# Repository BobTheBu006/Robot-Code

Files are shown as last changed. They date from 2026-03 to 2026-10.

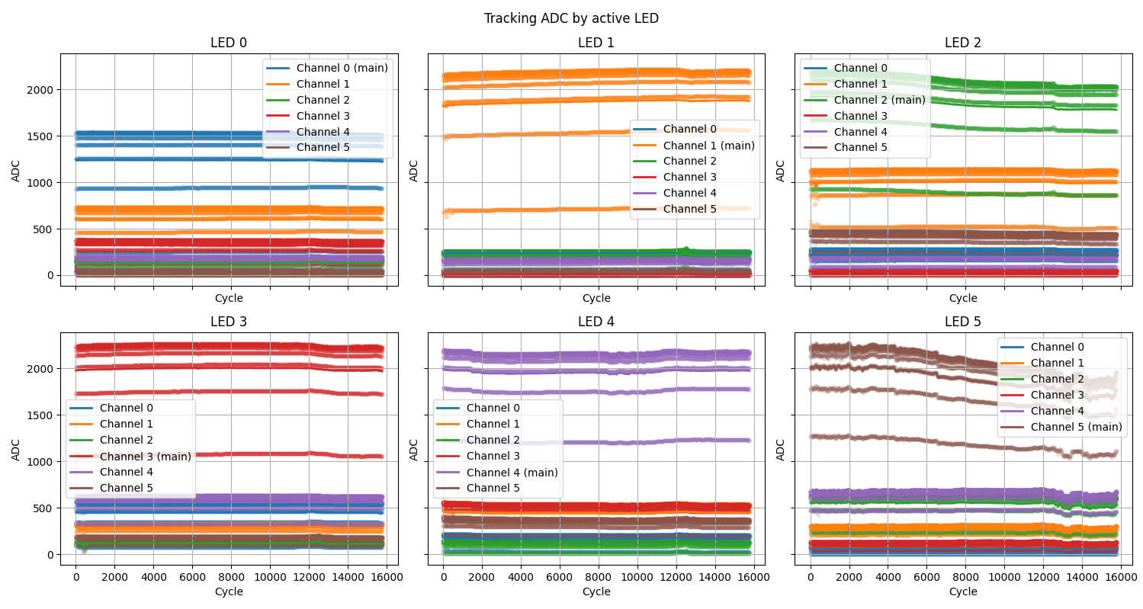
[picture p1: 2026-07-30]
OD tests/Figure_2.png

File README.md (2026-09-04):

# Modular Robot Control Platform

This repository is the working prototype for a modular, open-source lab robot platform aimed at underfunded research labs, universities, and small teams that need repairable automation built from cheap, available parts.

The long-term target is an extensible alternative to closed lab automation systems. The Raspberry Pi coordinates the robot, the browser UI edits workflows and hardware maps, and ESP32 controllers run the low-level motor, actuator, and sensor code.

## Thesis

The complete MSc thesis describing the robot's motivation, mechanical and electronic design, software architecture, commissioning, and experimental evaluation is available here:

- [Download the MSc thesis (PDF)](docs/thesis/MSc_Thesis.pdf)

## Start Here

For future AI coding agents and maintainers:

- Read `docs/ARCHITECTURE_CONTRACTS.md` before changing schemas, workflow behavior, firmware generation, or module boundaries.
- Read `docs/BACKWARDS_COMPATIBILITY.md` before changing saved workflows, hardware maps, manifests, or firmware protocols.

## Current Capabilities

- FastAPI backend with health, robot state, camera, hardware map, function discovery, ESP32 builder, and workflow storage routes.
- Vite + React + TypeScript frontend.
- React Flow workflow editor with built-in flow controls, advanced function blocks, and compound function blocks.
- Hardware Map editor for Raspberry Pi, ESP32 controllers, motors, servos, sensors, and grouped hardware assemblies.
- Function manifests can declare hardware dependencies so the Hardware Map and workflow blocks can reference the same logical devices.
- Workflow runs flash the ESP32 boards used by the workflow before execution.

## Repository Structure

```text
.
|-- backend/
|-- docs/
|-- firmware/
|-- frontend/
|-- functions/
|-- hardware/
|-- hardware-map.json
`-- workflows/
```

## Quick Start

Prerequisites:

- Python 3.11+ for the backend
- Node.js 20+ with `npm` for the frontend
- Arduino CLI for ESP32 build/flash flows

### Start Everything

Clone the repository and enter its directory:

```text
git clone https://github.com/BobTheBu006/Robot-Code.git
cd Robot-Code
```

On Windows 11:

```powershell
start-all.bat
```

On Raspberry Pi OS / Linux:

```bash
./start-all.sh
```

Frontend UI:

```text
http://127.0.0.1:5173
```

Backend API:

```text
http://127.0.0.1:8000
```

### Start Backend Only

```powershell
start-backend.bat
```

### Start Frontend Only

```powershell
start-frontend.bat
```

## Development Model

The intended architecture is modular:

- Hardware Map is the source of truth for physical USB ports, controllers, devices, pins, and hardware groups.
- Function manifests declare the devices they require.
- Basic workflow blocks are generated from hardware devices.
- Advanced functions can use controller firmware and backend handlers, but they must still declare hardware dependencies.
- Compound functions can be built from connected workflow blocks and should become exportable/shareable modules later.
- Firmware flashed to each controller should eventually be generated from the Hardware Map plus every workflow block that needs that controller.

Do not add one-off pin lists or hidden hardware assumptions inside functions. If a function uses a motor, servo, sensor, camera, API service, or future device, declare it through the module/function contract so the UI, backend, firmware, and tests can reason about it.

## License

This repository is licensed under Apache License 2.0 unless a file or module says otherwise. See `LICENSE` and `docs/LICENSE_POLICY.md`.

Future hardware/CAD/electronics packages should carry an explicit open hardware license, with `CERN-OHL-S-2.0` as the preferred default when the goal is to keep hardware improvements open.

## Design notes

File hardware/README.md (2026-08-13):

# Hardware

This directory contains the mechanical, electrical, and manufacturing files for
the modular laboratory robot.

## Structure

- `mechanical/`: original CAD, neutral STEP exports, and print-ready STL files.
- `electronics/`: schematics, PCB design files, and wiring documentation.
- `bom/`: bills of materials and sourcing information.
- `third-party/`: attribution and licence records for externally sourced models.

Each mechanical assembly uses the same export structure:

```text
assembly-name/
|-- source/  # Editable native CAD, such as F3D or F3Z
|-- step/    # Neutral CAD exchange files
`-- stl/     # Current print-ready parts
```

Use descriptive lowercase filenames with hyphens. Git records normal design
history, so avoid names such as `final-final` unless two revisions must remain
available at the same time.

Original hardware files should use the hardware licence declared by the
repository. Do not add third-party models until their source, author, licence,
and modification status have been recorded in `third-party/README.md`.

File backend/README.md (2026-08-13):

# Backend

FastAPI backend for the local robot-control app.

Read `../docs/ARCHITECTURE_CONTRACTS.md` and `../docs/BACKWARDS_COMPATIBILITY.md` before changing function discovery, hardware map sync, workflow execution, firmware flashing behavior, or persistent data contracts.

## Run locally

On Raspberry Pi OS / Linux:

```bash
cd "/home/robot/robot control/Robot-Code"
./start-backend.sh
```

On Windows 11:

```powershell
cd "C:\BOB\masters\Thesis\Robot Code"
start-backend.bat
```

Or run it directly:

Raspberry Pi OS / Linux:

```bash
cd "/home/robot/robot control/Robot-Code/backend"
python3 -m venv .venv
./.venv/bin/python -m pip install -r requirements.txt
./.venv/bin/python -m uvicorn app.main:app --reload
```

Windows 11:

```powershell
cd "C:\BOB\masters\Thesis\Robot Code\backend"
.\.venv\Scripts\python.exe -m pip install -r requirements.txt
.\.venv\Scripts\python.exe -m uvicorn app.main:app --reload
```

The API will be available at `http://127.0.0.1:8000`.

## Run the tests

Install the development requirements, then run the standard-library test suite:

Raspberry Pi OS / Linux:

```bash
./.venv/bin/python -m pip install -r requirements-dev.txt
./.venv/bin/python -m unittest discover -s tests -t .
```

Windows 11:

```powershell
.\.venv\Scripts\python.exe -m pip install -r requirements-dev.txt
.\.venv\Scripts\python.exe -m unittest discover -s tests -t .
```

## Endpoints

- `GET /health`
- `GET /api/robot/state`
- `POST /api/robot/state/mock-update`
- `GET /api/camera/status`
- `GET /api/camera/frame`
- `GET /api/camera/stream`
- `GET /api/functions`
- `POST /api/functions/{function_id}/test`
- `POST /api/esp32-builder/workflow-firmware/plan`
- `GET /api/tools/syringe/status`
- `POST /api/tools/syringe/dispense`

## Camera feed

The backend can expose a USB camera to the frontend as an MJPEG stream.

Camera environment variables:

- `CAMERA_DEVICE=0`
- `CAMERA_FRAME_WIDTH=1280`
- `CAMERA_FRAME_HEIGHT=720`
- `CAMERA_FPS=15`

If the camera feed reports that OpenCV is unavailable, reinstall backend dependencies:

```bash
cd "/home/robot/robot control/Robot-Code/backend"
./.venv/bin/python -m pip install -r requirements.txt
```

## Syringe ESP32 control

The backend can send a 7-head syringe dispense command to an ESP32 over serial.

Defaults:

- calibration file: `/home/robot/robot control/syringe control code/calibration.json`
- serial port: first match from `/dev/ttyUSB*` or `/dev/ttyACM*`
- baud rate: `115200`
- command format: `json`

Optional environment variables:

- `SYRINGE_CALIBRATION_FILE`
- `SYRINGE_SERIAL_PORT`
- `SYRINGE_BAUD_RATE`
- `SYRINGE_SERIAL_TIMEOUT_SECONDS`
- `SYRINGE_COMMAND_FORMAT`

Example request:

```bash
curl -X POST http://127.0.0.1:8000/api/tools/syringe/dispense \
  -H "Content-Type: application/json" \
  -d '{"A":150,"B":25,"C":0,"D":100,"E":0,"F":10,"G":75}'
```

## Function discovery

Robot execution blocks are discovered from subfolders in `backend/app/functions/`.

Each function folder must contain:

- `manifest.json`
- `handler.py`
- `requirements.txt`

Example structure:

```text
app/functions/
  dispense/
    manifest.json
    handler.py
    requirements.txt
```

The `GET /api/functions` endpoint scans those folders, validates their manifests, and returns the block metadata the workflow editor uses to build robot-action nodes.

`POST /api/functions/{function_id}/test` loads the function folder's `handler.py` and calls `execute(context, inputs)` in test mode so the workflow editor can preview block behavior without introducing a full execution engine yet.

Function manifest outputs are workflow control-flow paths, not data fields. Normal robot actions should expose a single `next` output with `"type": "flow"`; the Workflow Editor can add a separate `error` output from block settings. Branching blocks such as if/else or loops may expose multiple flow outputs. Handler return values such as status strings, measurements, or raw controller replies should remain in the result payload and should not be listed as graph outputs.

The Workflow Editor separates blocks into three groups:

- Basic blocks: triggers, logic blocks, and hardware-map generated servo/stepper/sensor actions.
- Advanced functions: backend-discovered robot functions such as gantry calibration and syringe dispensing.
- Compound functions: directly connected canvas blocks collapsed through the canvas context menu. Compound functions preserve their external flow outputs and can be expanded back into editable blocks.

Advanced function manifests may declare `hardware_devices`. Each declared motor, servo, or sensor is synchronized into the Hardware Map using stable device IDs and `function_input_key` pin links. The Workflow Editor then generates the matching basic hardware block from the Hardware Map, so a custom function and its basic move/read block point at the same physical USB controller and GPIO pins.

Advanced function manifests may also declare `firmware_requirements`. These identify the ESP32 routines, source files, protocols, and required logical devices that workflow-aware firmware planning collects per controller before flashing. The planner endpoint validates that referenced firmware sources stay inside the selected board workspace and exist before the workflow runner starts flashing boards.

## Mock update example

```powershell
Invoke-RestMethod -Method Post `
  -Uri http://127.0.0.1:8000/api/robot/state/mock-update `
  -ContentType "application/json" `
  -Body '{
    "machine_state": "running",
    "current_workflow": "tray_loading",
    "current_step": 4,
    "gantry": { "x": 210, "y": 85, "z": 32 },
    "sensor_values": [],
    "alarms": [
      {
        "code": "low_air",
        "message": "Compressed air pressure below threshold.",
        "severity": "warning",
        "active": true
      }
    ]
  }'
```

## Current design

- `app/api/routes/` contains route definitions
- `app/models/` contains Pydantic models for robot state and updates
- `app/services/` contains robot state, hardware map, function discovery, workflow storage, and ESP32 builder logic

This keeps routing, data contracts, and application logic separate from the start.

For future changes, keep persistent schema updates versioned and covered by migration tests. See `../docs/BACKWARDS_COMPATIBILITY.md`.

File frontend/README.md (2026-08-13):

# Frontend

Vite + React + TypeScript dashboard for the local robot-control app.

Requires Node.js 20+ with `npm` available on your `PATH`.

Read `../docs/ARCHITECTURE_CONTRACTS.md` and `../docs/BACKWARDS_COMPATIBILITY.md` before changing workflow, hardware map, block behavior, or persistent data contracts.

## Run locally

On Raspberry Pi OS / Linux:

```bash
cd "/home/robot/robot control/Robot-Code"
./start-frontend.sh
```

On Windows 11:

```powershell
cd "C:\BOB\masters\Thesis\Robot Code"
start-frontend.bat
```

Or run it directly:

Raspberry Pi OS / Linux:

```bash
cd "/home/robot/robot control/Robot-Code/frontend"
cp .env.example .env
npm install
npm run dev
```

Windows 11:

```powershell
cd "C:\BOB\masters\Thesis\Robot Code\frontend"
copy .env.example .env
npm.cmd install
npm.cmd run dev
```

## Environment

```env
VITE_API_BASE_URL=
```

Leave `VITE_API_BASE_URL` blank for normal development. The frontend will call `/api/...` on the same origin, and Vite proxies those requests to the FastAPI backend at `http://127.0.0.1:8000`. This is the correct setup when opening the UI from another computer on the Raspberry Pi network, because browser-side `127.0.0.1` would otherwise point at the other computer.

Once the backend camera route is enabled, the dashboard camera panel will pull its live stream from `/api/camera/stream`.

## Available scripts

- `npm run dev`
- `npm run build`
- `npm run preview`

## Current features

- backend connection status
- robot state polling every second
- robot state card with loading, success, and error feedback
- camera status and feed placeholder/live stream support
- Hardware Map editor for Raspberry Pi, ESP32 controllers, devices, pins, and hardware groups
- Workflow Editor with basic, advanced, and compound function blocks
- hardware-map generated basic blocks for steppers, servos, and sensors
- per-block inspector editing and function test actions
- palette block hide/unhide behavior
- pre-run ESP32 flashing for boards used by the workflow

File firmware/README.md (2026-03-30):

# Firmware Placeholder

This folder is reserved for future ESP32 firmware projects.

Likely future contents:

- one folder per ESP32 board
- shared protocol definitions
- hardware pinout notes
- board responsibilities

Nothing is implemented here yet on purpose.

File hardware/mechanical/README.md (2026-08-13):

# Mechanical Design

Mechanical files are grouped by robot assembly. Keep editable CAD in `source/`,
neutral exports in `step/`, and only current print-ready meshes in `stl/`.
The `whole-robot/` directory contains the maintained partial assembly that brings
the major subsystems together.

When adding a part, record its quantity, material, print orientation, support
requirements, and assembly notes in the relevant assembly directory.

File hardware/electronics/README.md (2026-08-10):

# Electronics

- `schematics/`: circuit and connection diagrams.
- `pcb/`: editable PCB projects and fabrication outputs.
- `wiring/`: cable, connector, pinout, and harness documentation.

Machine-specific secrets and local runtime configuration must not be stored
here.

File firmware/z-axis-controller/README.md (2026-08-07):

# Dual Z-Axis Controller Firmware

> **The canonical source now lives in the builder workspace:**
> `functions/esp 32 code/esp32 controller-ykkl80/firmware/main.ino`
>
> That is the copy the app compiles and flashes. Edit it there, not here.
> This directory is kept only as the recovery archive of where the firmware
> came from; the copy in it may lag behind.

Firmware for the "Double Z axis and pumps" ESP32 (hardware map board
`controller-ykkl80`). Drives two Z motors; the four limit switches are NOT
wired to this board - they go straight to Raspberry Pi GPIO, and the Pi
decides when to stop (see `backend/app/services/hybrid_z_axis.py`).

Originally recovered from `functions/esp 32 code/esp32 ttyUSB1/firmware/main.ino`,
the combined CoreXY+Z controller firmware from before the XY gantry moved to
Raspberry Pi GPIO. It still contains the XY/CoreXY command handlers; they are
harmless to leave in (never invoked) since this board only has Z motors wired.

Serial protocol (115200 baud):
- `SET Z PINS <leftStep> <leftDir> <rightStep> <rightDir>`
- `STEP Z <leftSteps> <rightSteps> <rpm> <trapezoidFlag> <accelRpmPerSec>`
  - Open-loop move; this board reads no limit switches for it. Replies
    `OK STEP Z <leftDone> <rightDone>` with the steps actually travelled, or
    `OK STOP STEP Z <leftDone> <rightDone>` if the host sent `STOP` mid-move.
  - The host seeks a switch by commanding the whole travel and sending `STOP`
    the instant its own GPIO sees the switch trip. `runDualAxisMove` checks for
    `STOP` between every step, so overtravel is one step period, and the axis
    moves smoothly instead of hopping between short bursts.
- `STOP` - abort the move in progress.
- `PING` -> `PONG`

**Do not send this board the limit-switch pin numbers from the Hardware Map.**
Those are Raspberry Pi GPIO numbers. `SET Z LIMITS` with them configures ESP32
GPIO 6, which is wired to this chip's internal SPI flash - it hangs the board
with a watchdog reset. The hybrid Z service never sends `SET Z LIMITS`.

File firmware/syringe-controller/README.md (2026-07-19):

# 7-Syringe Pump Controller Firmware

Firmware currently running on the pre-flashed syringe ESP32
(hardware map board `controller-x83xnc`, /dev/ttyUSB0).

Recovered from git history: last modified in commit fb4489e
("fixed advanced setting bugs also added parallel dispensing"),
back when it lived at `functions/esp 32 code/esp32 ttyUSB0/firmware/main.ino`
before that workspace was repurposed for the gantry firmware.

7 steppers: STEP pins 33/25/26/27/14/12/13, DIR pins 32/4/5/18/19/21/22.
Serial protocol (115200 baud): JSON/CSV dispense commands plus
SPEED / INTAKE SPEED / OUTTAKE SPEED — the backend's
syringe_controller.py speaks this protocol.

This board is deliberately NOT a builder workspace: the workflow firmware
planner treats it as externally programmed and never reflashes it. If you
ever need to reflash the syringe ESP32, use this source.

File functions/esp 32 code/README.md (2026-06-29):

# ESP32 Board Workspace Structure

Read `../../docs/ARCHITECTURE_CONTRACTS.md` before changing board workspaces, workflow-function blueprints, or firmware behavior.

Each connected board gets its own workspace folder:

```text
functions/esp 32 code/
  README.md
  esp32 ttyUSB0/
    board.json
    NOTES.md
    firmware/
      main.ino
    workflow-functions/
      dispense.json
```

## What each file does

- `board.json`: metadata for the board and the serial port currently associated with it.
- `firmware/main.ino`: the local Arduino source edited from the Robot Control UI or directly in the board workspace.
- `workflow-functions/*.json`: blueprint files that generate workflow block manifests for the canvas.

## Build and flash flow

1. Edit `firmware/main.ino` or one of the workflow-function blueprint JSON files.
2. Save the file.
3. Use `Build firmware` to compile the sketch on the Pi.
4. Use `Build + Flash` to upload it to the connected ESP32 on the configured serial port.

Most ESP32 dev boards can enter the bootloader automatically through the USB serial adapter's DTR/RTS lines. If upload ever fails to connect, hold the board's `BOOT` button as flashing starts and release it once the upload begins.

The long-term target is workflow-aware firmware assembly: each controller should be flashed with all routines needed by the active workflow, based on the Hardware Map and the blocks used in that workflow.

## Blueprint format

Each blueprint file should contain:

```json
{
  "manifest": {
    "id": "dispense",
    "display_name": "Dispense Syringe Batch",
    "category": "Robot Actions",
    "description": "High-level syringe dispense action.",
    "version": "0.1.0",
    "inputs": [],
    "hardware_devices": [],
    "outputs": [
      {
        "key": "next",
        "label": "Next",
        "type": "flow",
        "description": "Continue when this action completes."
      }
    ]
  },
  "advanced_builder_inputs": [],
  "firmware_entry_file": "firmware/main.ino",
  "protocol": "serial-text"
}
```

## How blocks are created

1. The Pi scans every `workflow-functions/*.json` file.
2. The `manifest` section is synced into `backend/app/functions/<id>/manifest.json`.
3. If the function folder does not exist yet, the Pi creates a placeholder handler.
4. The normal `/api/functions` discovery endpoint then exposes that block to the workflow editor.

## Recommended split

- Put runtime parameters in `manifest.inputs`.
- Use `manifest.outputs` only for control-flow paths. Normal robot actions should have one `next` flow output; use the block settings error path for failures. Do not add outputs for returned data like status text, measurements, or raw controller replies.
- Put firmware tuning, pins, and board-wiring fields in `advanced_builder_inputs`.
- Put required controller routines in `manifest.firmware_requirements`. Use stable routine IDs and point at the firmware source or fragment that must be included when a workflow uses the block.
- Put every actuator, motor, servo, or sensor the function uses in `manifest.hardware_devices`. Use stable device IDs that match the Hardware Map, and set each pin's `function_input_key` to the matching runtime or advanced input. The Hardware Map creates or updates those devices so function inputs can be resolved from the real wiring.
- Advanced functions should reference shared Hardware Map devices instead of keeping an unrelated private pin list. If a function moves syringe head A, it should declare/reference the same `syringe-head-a` device used by the physical hardware map.
- Treat hardware and code as related but separate. The same syringe pump hardware can support multiple firmware routines and workflow functions.
- Keep actual source code changes in `firmware/main.ino`.
- Use `board.json` to override the active `fqbn` or firmware entry file for a specific board workspace if needed.

## Workflow block types

- Basic blocks come from the editor itself and from the Hardware Map. Adding a stepper motor creates a basic stepper move block. Adding a servo creates a basic servo angle block using the servo rotation range from the Hardware Map. Adding a sensor creates a basic sensor read block.
- Advanced functions come from these ESP32 workflow-function blueprints and run through the backend function endpoint.
- Compound functions are made in the Workflow Editor by selecting directly connected blocks, right-clicking the selection, and choosing `Create compound function`.

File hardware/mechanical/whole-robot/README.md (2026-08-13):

# Whole Robot Assembly

`source/assembled-robot.f3z` is the editable Autodesk Fusion archive for the
partial whole-robot assembly. It brings the major robot subsystems together in
one model, but it is not yet a complete or fabrication-ready representation of
every installed component.

This is a living hardware source model. It will continue to be maintained after
the thesis submission as the assembled robot and its subsystem designs evolve.
Update this archive deliberately and describe material assembly changes in the
commit message.

The F3Z archive is stored with Git LFS because native CAD revisions are large
binary files. Install Git LFS before cloning or pulling this model.

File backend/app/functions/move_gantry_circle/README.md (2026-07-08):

# Move Gantry Circle

Traces a full circle with the CoreXY gantry around a given center position.

- `center_x_cm` / `center_y_cm`: absolute circle center in workspace cm.
- `radius_cm`: circle radius in cm; the whole circle must fit inside the calibrated workspace.
- `repeat_count`: number of full circles to trace before continuing.
- `speed_rpm`: target motor speed, ramped with `acceleration_rpm_per_s` over the whole lap when `trapezoidal_speed` is on.

The gantry first moves in a straight line to the circle start point (center X + radius, center Y),
then follows the circle counter-clockwise in ~0.5 mm chords and stops back at the start point. When
`repeat_count` is greater than 1, it repeats the full-circle move that many times.
Requires a prior Calibrate Gantry XY run. Any limit switch press stops the move immediately.

Serial protocol: `CIRCLEXY <centerXCm> <centerYCm> <radiusCm> <rpm> <trapezoidFlag> <accelerationRpmPerSecond>`,
completing with `OK CIRCLE XY`.

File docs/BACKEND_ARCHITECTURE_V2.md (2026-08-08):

# Backend Architecture v2

Target structure for the control backend. This document is the agreed plan; it
supersedes nothing in `ARCHITECTURE_CONTRACTS.md` — it is how those contracts
actually get implemented.

## Decisions

| Decision | Choice |
| --- | --- |
| Blast radius | Keep the hardware drivers, replace the orchestration above them |
| Firmware | Identity + fingerprint handshake and preflight now; code generation next |
| Parallel branches | Genuinely concurrent, gated by logical resource locks |
| Verification | Simulation-first; no hardware available during development |

### Why the drivers stay

`raspberry_gantry.py`, `gantry_controller.py`, `hybrid_z_axis.py` and
`syringe_controller.py` are roughly 180 KB of hardware-tuned code: CoreXY step
timing, trapezoidal acceleration, limit probing with fast-touch/backoff/slow-touch,
partial-travel adoption after an aborted move. That behaviour was tuned against
the physical machine and cannot be re-derived without it.

Everything above them — scheduling, safety arbitration, controller identity,
function discovery, packaging — is what actually misbehaves, and all of it is
testable without hardware. So v2 rebuilds the orchestration layer and wraps the
drivers behind explicit ports.

## Root causes being fixed

These are the specific defects v2 exists to remove. Each is referenced by the
phase that closes it.

| # | Defect | Where | Phase |
| --- | --- | --- | --- |
| 1 | No backend execution engine; the runner is in the browser | `WorkflowEditorCard.tsx` | 3 |
| 2 | `ok=True` hardcoded, so handler failure reads as success | `function_discovery.py` `test_function` | 3 |
| 3 | Run order is a DFS over edge-array order | `collectRunAllOrder` | 3 |
| 4 | Joins fire on the first arriving branch | `collectRunAllOrder` | 3 |
| 5 | `if`/`while`/`for` run every successor; loops never loop | `collectRunAllOrder` | 3 |
| 6 | `error` edges traversed during healthy runs | `collectRunAllOrder` | 3 |
| 7 | Only 5 hardcoded block ids receive upstream JSON | `blockUsesUpstreamInput` | 3 |
| 8 | `result.ok` never checked; a failed block does not stop the run | `runOrderedWorkflowNodes` | 3 |
| 9 | `failureMode` / `retryCount` are edited but never consumed | workflow settings | 3 |
| 10 | Disabled hardware yields `ok:true`, run continues | `getDisabledHardwareReason` | 4 |
| 11 | Five independent E-Stop latches; `/rearm` clears two | `emergency_stop.py` | 1a |
| 12 | Every block run silently un-latches E-Stop | `startNewActivity` | 1a, 5 |
| 13 | Toolhead state is written only on success, then forced to `None` | `toolhead.py`, `emergency_stop.py` | 1b |
| 14 | `cancel` targets a freshly re-imported module, not the running one | `_load_handler_module` | 3 |
| 15 | Two controller-ID namespaces; unmatched boards silently skip flashing | `esp32_builder.py` | 2 |
| 16 | Firmware plan is computed then discarded; static `main.ino` flashed | `flash_firmware` | 2 (partial), later (full) |
| 17 | `GET /api/functions` rewrites the hardware map mid-run | `function_discovery.discover` | 3 |
| 18 | POSIX-only `/tmp` and `killpg` | `esp32_builder.py` | 2 |
| 19 | Workflows embed frozen block definitions (820 KB files) | workflow JSON | 5 |
| 20 | `hardware-map.json` has no `schema_version` | `hardware_map.py` | 2 |

## Target layout

```text
backend/app/
  core/
    safety.py           SafetyController: the single motion latch
    config.py
    env_file.py
  engine/
    graph.py            workflow JSON -> validated ExecutionGraph
    plan.py             ExecutionGraph -> ExecutionPlan (hardware + firmware resolved)
    scheduler.py        ready-set scheduling, join barriers, loop scopes
    resources.py        logical resource derivation + ordered lock acquisition
    runtime.py          RunContext handed to handlers
    runs.py             run store, journal, event stream
  controllers/
    registry.py         controller identity, USB-serial binding, port resolution
    fingerprint.py      firmware bundle hashing
    handshake.py        ID? / PONG protocol, preflight compare
    transport.py        SerialTransport port + SimulatedTransport
  packages/
    <package_id>/
      package.json      shared device roles, naming, resources
      functions/<function_id>/{manifest.json,handler.py}
  services/            (existing drivers, wrapped not rewritten)
  api/routes/
```

## The pieces

### 1. Safety is one authority

`SafetyController` is a process singleton owning a single latch:

```text
armed -> stopping -> latched -> recovering -> armed
```

Everything that can produce motion registers as a `StoppableActor`
(Pi GPIO service, each open serial session, each flash subprocess). E-Stop sets
the latch, then fans out `stop()` to every registered actor. Every motion entry
point consults exactly one flag.

Rules:

- Clearing the latch is an explicit operator action. Starting new work must
  never imply it. This removes the auto-rearm that made E-Stop advisory.
- `GET /api/safety` exposes latch state, which actors reported, and what
  physical state became uncertain, so the UI can show it and refuse to run.
- Rearm is refused while any physical state is still `uncertain` and
  unconfirmed.

### 2. Physical state carries certainty

Physical facts are three-valued, not two-valued. `PhysicalStateStore` records
each fact as `{value, certainty: known|uncertain, reason, updated_at}` and is
written as **intent before motion**, then confirmed after:

```text
before pickup:  {held: 3, certainty: uncertain, phase: "engaging"}
after success:  {held: 3, certainty: known}
after E-Stop:   {held: 3, certainty: uncertain, reason: "estop during engage"}
```

An E-Stop therefore no longer claims the head is empty. The next `pickup`
refuses until the operator confirms what is physically on the gantry, instead of
driving a loaded head into the rack. Same treatment for gantry calibration and
Z position.

### 3. Controller identity is the Hardware Map ID

One namespace. The Hardware Map's `controller-*` id is the only controller
identity; it is bound to the USB descriptor serial number. The port is a runtime
lookup, never an identity. `_board_id_from_port` is deleted and the existing
`esp32 ttyUSB0` / `esp32 ttyUSB1` / `esp32 controller-ykkl80` workspaces are
migrated to `firmware/controllers/<controller_id>/`.

### 4. Firmware fingerprint is the ping

A controller's expected firmware is hashed into a `fingerprint` over the
canonicalised routine set, the resolved pin table, and the source contents. The
firmware answers `ID?` with:

```json
{"controller_id": "...", "fingerprint": "...", "protocol": 2, "routines": ["..."]}
```

That one reply is the liveness check, the identity check, and the "is the right
code actually on it" check. Preflight resolves each controller by serial number,
asks `ID?`, compares, and **flashes only on mismatch** — so flashing becomes
rare instead of happening before every run. A controller that answers with the
wrong `controller_id` is a hard error, never a silent warning.

Code generation (per-controller `generated_config.h` + `generated_routines.h`
emitted from the Hardware Map, with cross-controller routines fanned out to
every controller owning a required device) is the next pass. The fingerprint
schema is designed now so that generation slots in without changing the
protocol.

### 5. The engine executes a graph as a graph

Compile before moving. `ExecutionPlan` is built and validated up front:
hardware resolved, firmware preflighted, cycles outside loop scopes rejected,
unreachable nodes reported, joins identified. Blocking errors surface before
anything moves rather than mid-motion.

Then schedule:

- A node is ready when every **activated** incoming flow edge has delivered.
- Control blocks activate only the edge they chose, so `if` runs one branch.
- Fan-out spawns concurrent tasks; fan-in is a real join barrier.
- `while` / `for` / `loop_over` are re-entrant scopes with an iteration counter
  and a max-iteration guard.
- Every step receives `{"$in": <merged upstream>, "$run": {...},
  "$blocks": {node_id: result}}` and uses the parts it cares about.
- Per-node policy is honoured: `timeout`, `retry(n, backoff)`,
  `on_error: stop | continue | error_path`.

### 6. Resource locks make parallelism safe

Each function declares the logical resources it needs, derived from its devices:
`gantry.xy`, `z.left`, `syringe.head_b`, `controller:<id>:serial`. The scheduler
acquires them in a fixed global order before running a node, so:

- two branches that both want `gantry.xy` serialise automatically
- a Z move and a syringe dispense genuinely overlap
- deadlock is impossible (total order over resource ids)

This is what makes "a split runs in parallel" a safe statement about a machine
with one physical gantry.

### 7. Packages own hardware families

A package owns the shared device set, the pin/variable naming scheme, and the
shared inputs for one hardware assembly:

| Package | Functions |
| --- | --- |
| `gantry_xy` | calibrate, move_xy, move_circle, test_repeatability |
| `z_axis` | calibrate, move |
| `toolchanger` | pickup, drop |
| `syringe_7` | dispense, prime, wash, calibrate |
| `controller` | connect, disconnect, test_motor |

Device **roles** carry `required: true|false` and a `min_required` count — the
granularity hook. `syringe_7` declares `head_a..head_g` all optional with
`min_required: 1`, so disabling head B removes only head B. `z_axis` declares
`z_left`/`z_right` optional with `min_required: 1`, so a disabled left Z leaves
the right one movable. Degradation is reported in the result payload and in the
preflight report; it never silently reads as full success.

### 8. Run API

```text
POST   /api/runs                     -> run_id      (workflow, mode: run|dry_run)
GET    /api/runs/{id}                -> snapshot    (for reconnect)
GET    /api/runs/{id}/events         -> SSE         (node/phase/log/safety events)
POST   /api/runs/{id}/cancel
POST   /api/runs/{id}/pause | /resume
POST   /api/runs/{id}/resume-from/{node_id}
GET    /api/safety                   -> latch state + uncertain physical state
POST   /api/safety/stop | /rearm
POST   /api/safety/confirm-physical-state
```

Runs journal to append-only JSONL, so a backend restart can still say what
happened and where it stopped.

## Getting back on track

The "if there is a problem, get back on track" requirement is met by four
mechanisms, in order of preference:

1. **Preflight** — the plan refuses to start when hardware, firmware or graph
   structure is wrong, and says exactly what to fix.
2. **Per-node policy** — timeout, retry with backoff, and an explicit error path
   handle the recoverable cases without operator involvement.
3. **Certainty tracking** — anything a fault made unknowable is marked
   uncertain rather than guessed, and blocks resume until confirmed.
4. **Journal + resume-from** — a stopped run can be inspected and restarted from
   a chosen node instead of from the beginning.

## Phases

| Phase | Content | Closes |
| --- | --- | --- |
| 1a | SafetyController, `GET /api/safety`, explicit rearm | 11, 12 |
| 1b | PhysicalStateStore with certainty; toolhead fix | 13 |
| 1c | Simulation transport (simulated ports + firmware responder) | — |
| 2 | Controller registry, fingerprint handshake, preflight, schema_version | 15, 18, 20; 16 partially |
| 3 | Run engine, resource locks, run API + SSE, cached handlers | 1–9, 14, 17 |
| 4 | Function packages, role-level degradation | 10 |
| 5 | Frontend becomes a viewer; workflows stop embedding definitions | 12, 19 |

Simulation is Phase 1c rather than last because with no hardware on the bench it
is the prerequisite for verifying every phase after it.

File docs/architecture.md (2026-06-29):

# Architecture Overview

## Purpose

The platform is a local-first robot-control system for modular lab automation. It should make physical hardware, controller firmware, backend functions, and visual workflows fit together through explicit contracts instead of hidden wiring assumptions.

## Runtime Shape

```text
Operator browser
  |
  v
React frontend
  |
  v
FastAPI backend on Raspberry Pi
  |
  +-- saved workflows
  +-- hardware map
  +-- function discovery and handlers
  +-- ESP32 firmware build/flash orchestration
  |
  v
ESP32 controllers
  |
  v
motors, servos, sensors, tools, future modules
```

## Main Components

### Frontend

The frontend is a Vite + React + TypeScript app.

Responsibilities:

- render operator dashboard panels
- edit the Hardware Map
- edit workflows with block diagrams
- expose block settings and function inputs
- call backend APIs for function discovery, workflow storage, hardware map storage, and ESP32 flash/run actions

### Backend

The backend is a FastAPI app.

Responsibilities:

- validate API contracts with Pydantic models
- discover backend function folders
- sync declared function hardware into the Hardware Map
- persist workflows and hardware map JSON
- build and flash ESP32 workspaces
- run or test backend function handlers

### Hardware Map

The Hardware Map owns the physical model:

- Raspberry Pi
- controllers
- USB ports
- devices
- pins
- groups

Functions and firmware should reference logical devices from the Hardware Map instead of carrying private pin maps.

### Workflow Editor

The Workflow Editor owns process logic:

- Basic blocks represent built-in control logic and direct hardware operations.
- Advanced functions represent backend/firmware-backed robot actions.
- Compound functions represent selected connected blocks collapsed into a reusable block.

Workflow edges represent control flow. Data should be passed through parameters, context, or result payloads, not through extra graph handles unless a future typed-data-edge contract is explicitly designed.

### Firmware

ESP32 firmware is the low-level execution layer.

Target design:

- collect all workflow blocks used in a run
- group block firmware requirements by controller
- generate or assemble one firmware image per controller
- include all routines needed by that workflow for that controller
- flash each required controller once before the workflow starts
- execute routines by command during the workflow

## Data Ownership

| Data | Source of truth |
| --- | --- |
| USB port to controller mapping | Hardware Map |
| controller to device mapping | Hardware Map |
| device pin mapping | Hardware Map |
| advanced function metadata | function manifest |
| function hardware needs | function manifest, synced into Hardware Map |
| workflow process | workflow JSON |
| controller firmware source | board workspace and future module firmware requirements |
| user secrets | backend environment or secret store, not workflow JSON |

## Extension Direction

New capability should enter through one of these boundaries:

- new hardware device type
- new advanced function manifest and handler
- new firmware routine
- new compound function
- future module package

Avoid adding new hidden side channels. If a feature needs hardware, declare hardware. If it needs firmware, declare firmware requirements. If it needs saved state, version the schema.

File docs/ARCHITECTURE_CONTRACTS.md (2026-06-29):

# Architecture Contracts

These contracts are intended to stay stable from the public `v0.1 beta` release through the `v1.x` series. A hypothetical `v2` may fix deeper architecture problems, but it should still provide migrations for saved projects.

## Contract 1: Hardware Map Is Physical Truth

The Hardware Map owns physical wiring and grouping:

- USB port to controller
- immutable controller IDs
- Raspberry Pi GPIO/I2C direct device wiring
- controller to device
- device kind
- device logical ID
- device pins and signal names
- device calibration metadata such as pump mL per 200 motor steps
- function-to-hardware assignments that bind a function's required logical devices to physical Hardware Map devices
- hardware canvas block positions for operators' saved layout
- controller/device groups
- enabled/disabled state for controllers, devices, and groups

Functions, firmware, and workflow blocks must not treat private pin maps as the source of truth. They may provide defaults or requirements, but the Hardware Map resolves the actual physical setup.

Workflow function blocks must not expose controller selection, USB port selection, "Selected ESP32", or GPIO pin selection as normal per-block operator settings. Those values are derived from the function's logical hardware devices and the Hardware Map at execution/firmware-planning time.

When a function declares required hardware that is missing from the Hardware Map, the sync path may create a disabled, unconnected device placeholder. It must not create a guessed controller or silently connect that placeholder to an existing controller. Operators bind functions to real devices through the function-to-hardware assignments in the Hardware Map.

Devices wired directly to the Pi use `board_id: raspberry-pi`. This is a virtual controller ID and must not create a duplicate ESP32/controller block.

Devices with an empty `board_id` are intentionally unconnected. The UI must keep them visible so they can be reconnected instead of silently deleting or reassigning them.

Disabled hardware is intentionally unavailable but still part of the project. It must stay visible in the Hardware Map and must not be silently removed from workflows. Workflow blocks that depend on disabled hardware should be disabled with a clear reason, skipped from firmware planning/flashing, and blocked from direct execution until the hardware is enabled again.

Controller, device, and group IDs must be unique across the Hardware Map. Controller IDs are internal stable references generated by the system and should not be edited by operators; users change the USB port binding instead. Disabled controllers must not reserve a USB port for active controller selection.

The current gantry model is CoreXY, not independent left/right or independent X/Y motors. The stable `x-axis-motor` and `y-axis-motor` IDs are compatibility names for CoreXY A and CoreXY B motors. The normal Cartesian gantry coordinate system is X/Y/Z in centimeters from the back-bottom-left origin, with a current nominal work envelope of 115 cm x 60 cm x 60 cm.

## Contract 2: Logical Device IDs Are Stable

Device IDs are the durable bridge between:

- hardware map entries
- advanced function manifests
- firmware generation
- saved workflows

Do not rename IDs casually. If an ID changes, provide an alias or migration.

## Contract 3: Functions Declare Hardware Dependencies

Any function that uses hardware must declare it in `manifest.hardware_devices`.

Each declared device should include:

- stable `id`
- user-facing `name`
- `kind`
- optional `sensor_kind`
- optional `board_id`
- required signal rows in `pins`
- optional calibration metadata such as `calibration_ml_per_200_steps` for peristaltic pump steppers
- optional `function_input_key` links for fields that can be configured by function inputs
- optional `basic_block_id` for the generated primitive block

Advanced function code may still contain behavior, calibration, and command logic. It must not become the only place where hardware requirements are known.

## Contract 4: Hardware And Code Are Related But Not Married

A hardware assembly can support many functions.

Example: a 7-syringe pump is hardware. Dispense, prime, wash, calibrate, mix, and maintenance actions are different code routines that may all target the same hardware map.

When a workflow runs, the controller firmware should contain every routine required by all blocks targeting that controller.

## Contract 5: Workflow Outputs Are Control Flow

Graph outputs are flow-control paths.

Normal robot-action blocks should expose:

- `next`

Failures should use the block settings error path unless the block is explicitly a branching/logic block.

Motion blocks should prefer explicit numeric motion parameters such as RPM and acceleration over opaque speed presets. If a preset field is kept for backwards compatibility, new UI should present the numeric fields.

Allowed multi-output blocks include:

- if/else
- while/loop
- switch/case
- wait-until with timeout path
- API call with success/error/timeout paths if that is modeled as branching flow

Do not add handles for returned data such as status, measurements, or raw controller replies. Put those values in the result payload or workflow context.

## Contract 6: Compound Function Outputs

Compound functions are made from directly connected selected workflow blocks.

A compound block exposes the unconnected non-error flow outputs of the internal blocks. Internal error paths should stay internal unless the compound function explicitly exposes an error policy.

Compound functions must remain editable. Uncompounding should restore the internal block graph when possible.

## Contract 7: API Calls Are Workflow Blocks

External API calls should be normal workflow blocks.

The block contract should support:

- method
- URL or service ID
- headers
- request body
- timeout
- response mapping
- success path
- error or timeout path

Secrets must not be stored directly in workflow JSON. Store secret values in backend environment variables or a future secret store, and let workflows reference secret names.

## Contract 8: Firmware Is Per-Controller And Workflow-Aware

The firmware build/flash step should be driven by:

- the active workflow
- blocks used by that workflow
- hardware devices referenced by those blocks
- Hardware Map pin assignments
- `firmware_requirements` declared by modules/functions

The backend should build or assemble one firmware image per controller and flash each used controller before workflow execution. The image must include every routine needed by that controller during the workflow, not only the first block that uses it.

Only controllers present in the Hardware Map should be flashed. If the Hardware Map has no ESP32 controller boards for the workflow, the run must skip flashing and continue directly to execution. Stale manifest `builder_board_id` values are not enough to flash a board.

Each firmware requirement should carry a stable `routine_id`, controller targeting role, source file or fragment, protocol, optional entry point, and any required logical device IDs.

Current implementation note: `POST /api/esp32-builder/workflow-firmware/plan` is the backend boundary for collecting and validating per-controller requirements before flashing. Future code generation should extend this plan into actual assembled firmware images instead of introducing a separate path.

## Contract 9: E-Stop Is Highest Priority

The operator UI must keep an E-Stop control visible independent of page scroll or canvas state.

When E-Stop is pressed, the frontend must immediately abort in-flight workflow requests and the backend must immediately send a stop command to every active controller session it knows about. Controller firmware should treat `STOP` as a highest-priority command and stop motion before normal command completion handling.

During normal gantry motion, an unexpected physical limit-switch hit is treated as the same class of immediate stop fault. Calibration routines are the exception: they intentionally probe limit switches using controlled fast-touch, backoff, and slow-touch motion to define workspace boundaries.

## Contract 10: Missing References Stay Visible

If an old workflow references a missing function, module, device, controller, pin, or firmware routine:

- load the workflow anyway
- show a broken placeholder
- explain what is missing
- suggest a repair path

Do not silently delete blocks or edges from saved workflows.

## Contract 11: Modules Are Contract Packages

Future modules may live in this repository, a local folder, or a Git repository.

A module package should be able to declare:

- module ID and version
- compatible platform schema versions
- function manifests
- hardware templates
- firmware routines or firmware fragments
- backend handlers
- frontend UI extensions
- example workflows
- 3D/CAD models
- simulation hooks
- tests
- license

Do not split modules into separate repositories until the import/build/test workflow is clear enough to reduce maintenance work instead of increasing it.

## Contract 12: Simulation Is A First-Class Future Target

Simulation should eventually use the same contracts as real hardware:

- Hardware Map for device structure
- 3D/CAD models for geometry
- function manifests for behavior surface
- firmware or simulated controller routines for low-level behavior
- workflow JSON for process logic

Do not design simulation-only APIs that bypass the Hardware Map.

## Contract 13: Schema Versions Are Required For Persistent Data

Persistent project files must carry a schema version before `v0.1 beta`.

Applies to:

- hardware maps
- workflows
- function manifests
- module manifests
- firmware protocol descriptors
- future schematic imports
- future simulation model descriptors

When changing a persisted schema, add migration logic and tests.

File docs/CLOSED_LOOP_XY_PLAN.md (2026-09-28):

# Closed-loop XY: implementation plan

Written for the agent implementing this. Read all of it before starting stage 0
— the decisions in "Architecture" were made deliberately with the owner and are
not up for re-litigating mid-build.

The goal is **true closed-loop control**: position error is corrected
*continuously during a move*, not after it. PID, tuned later on the machine.

---

## Why this exists

The CoreXY motors lose steps. The bearings are worn and will get worse, and the
owner has said replacing them is not imminent. Today the machine only discovers
this at a tool change, when the X and Y re-home probes measure the accumulated
drift and reset it (see `_rehome_axis` in `raspberry_gantry.py`). That is a
backstop, not a fix — between tool changes the position quietly degrades, and a
stall mid-move is silent.

Encoders on the motor shafts make the loss visible as it happens, and let the
firmware put the steps back.

---

## Hardware

| Item | Detail |
| --- | --- |
| Controller | A **third ESP32**, dedicated to XY. Confirm availability before starting. |
| Encoders | 2 × **AS5600** magnetic encoder modules (magnet included), one per motor. Procurement changed from the AS5047D (SPI, 14-bit) on 2026-09-28. The AS5600 is **12-bit over I2C at a fixed address (0x36)**, so the two encoders cannot share a bus: encoder A runs on the ESP32's I2C controller 0 (`Wire`), encoder B on controller 1 (`Wire1`), each with its own SDA/SCL. Tie each module's DIR pin to GND or 3V3 — never floating — and leave OUT unconnected. |
| Magnets | `AS5000-MD6H-2` diametric, 6 × 2.5 mm — ships with each kit |
| Mounting | On the **A and B motor shafts**. Not on belt idlers — see below. |
| Drivers | Existing TB6600s, step/dir, shared active-low ENABLE |
| Limits | The four XY switches **move off the Pi onto this ESP32** |

### Pin budget (~13, comfortable on an ESP32)

- 2 × step + 2 × dir = 4
- 1 × shared driver enable = 1
- 4 × limit switches = 4
- I2C: 2 × (SDA + SCL), one bus per encoder = 4

Avoid GPIO 6–11 (flash), 34–39 (input only), 1/3 (UART to the Pi), and the
strapping pins 0, 2, 5, 12, 15. On a WROVER module also avoid 16/17 (PSRAM).
Record the final choice in `hardware-map.json`, never in code.

### Why motor shafts and not belt idlers

Each encoder then maps 1:1 to one motor, so there are **two independent PID
loops** with no coordinate transform. Measuring the axes instead would mean
every correction goes through the CoreXY transform (`a = x+y`, `b = x-y`),
coupling the two loops, and would put belt compliance *inside* the loop — the
usual source of oscillation. The trade accepted: this cannot detect belt slip
or a pulley slipping on its shaft. Those remain the tool-change re-home's job.

---

## Architecture decisions (settled — do not change without asking)

1. **The Pi-driven XY path stays.** `raspberry_gantry.py` keeps working and the
   hardware map chooses which path is live, exactly as it already does via
   `xy_hardware_is_on_raspberry_pi(context)`. This is the fallback if the loop
   misbehaves, and it is where today's tool-change re-home, drift reporting and
   direction-aware limit guard live. Do not delete or degrade it.
2. **Limit switches move to the XY ESP32.** Nothing in the control loop crosses
   the serial link. This frees Pi GPIO 20, 21 and 26.
3. **Following error halts the machine** past a tunable threshold. A stall must
   be loud. Never silently keep correcting into an obstruction.
4. **Extend the existing protocol.** The ESP32 XY firmware already has
   `SET XY PINS`, `SET XY LIMITS`, `MOVE XY`, `CALIBRATE XY`, and
   `gantry_controller.py` already drives them. Add to that vocabulary; do not
   invent a parallel one.

---

## The control design

### The hard constraint

A step/dir driver accepts **only step pulses**. There is no torque command. So
the loop cannot be a textbook servo — it works like a commercial closed-loop
stepper (iHSS57 and similar): a trajectory says where the axis *should* be, the
encoder says where it *is*, and PID trims how many steps get emitted.

```
trajectory(t) ──► target_steps ──┐
                                 ├──► error ──► PID ──► correction_steps
encoder ──► actual_steps ────────┘                          │
                                                            ▼
                              step generator setpoint = target + correction
                                          │  (rate-limited)
                                          ▼
                                     STEP/DIR pins
```

### Units

- AS5600 is **12-bit: 4096 counts/revolution**
- Motors run **800 steps/revolution**
- So **5.12 encoder counts per full step** — single-step loss is still visible,
  though with a quarter of the AS5047D's margin; half-step noise sits closer
  to the signal, so tune the following-error limit on the machine
- Do all loop maths in **encoder counts**, convert to steps only when emitting

### The three things that must be true

1. **Loop rate 1 kHz**, on a dedicated FreeRTOS task pinned to core 1, or a
   timer ISR. It must not be blocked by serial handling.
2. **Step generation must be non-blocking.** This is the largest single piece of
   work. `runDualAxisMove` today is a blocking loop built on
   `delayMicroseconds` (see `main.ino` ~line 203) — a control loop cannot run
   inside it. Replace with a high-rate timer ISR (~100 kHz) holding a phase
   accumulator per axis, emitting a pulse when one is due.
3. **The PID output must be rate-limited.** A correction spike that commands
   steps faster than the motor can follow causes *more* loss, not less. Clamp
   the emitted step rate to the same ceiling a normal move uses.

### PID specifics

- Error term in encoder counts; output in steps
- **Derivative on measurement, not error** — avoids a kick when the setpoint moves
- **Integral clamped** (anti-windup), and **frozen while the output is saturated**
- Start with `Kp` small, `Ki = 0`, `Kd = 0`; the owner tunes on the machine
- Gains, the following-error limit and the loop rate are all **settings**, not
  constants — reachable over serial and stored in the hardware map

---

## Stages

Each stage ends in something testable on the machine. Do not start a stage
until the previous one is proven on hardware.

### Stage 0 — bring-up, no motion

**Goal:** the board exists, is identified, and nothing moves.

- New ESP32 workspace under `functions/esp 32 code/`, following the existing
  layout. Give it a controller id and let the identity handshake work — the
  `ID?` handler and fingerprint machinery already exist and must not be bypassed.
- Add the board and its devices to `hardware-map.json`: two steppers, four limit
  switches, two encoders, one shared enable.
- Wire the enable line into `motor_power_service` as its own power domain, the
  way `raspberry_gantry.py` does. **Check the polarity on the machine** — the
  TB6600s are active-low, and getting this backwards is silent (see
  `_register_power_domain`).

**Acceptance:** `POST /api/esp32-builder/boards/<id>/preflight` returns `ok`;
the board reports its identity; no motor is energised.

### Stage 1 — read and report

**Goal:** trustworthy position from both encoders.

- I2C driver for the AS5600: one 3-byte read from STATUS (0x0B) returns the
  magnet state (MD/ML/MH) and RAW ANGLE (0x0C/0x0D) together. A missing magnet,
  or one too near or too far, is a read fault. Verify registers against the
  datasheet — do not trust this document for them.
- **Polling over I2C** at 400 kHz costs roughly 0.1–0.2 ms per encoder read,
  about ten times an SPI frame. That is why the loop reads every N step
  iterations rather than every one; measure the real cost on the machine
  before shortening N. The bus has a 2 ms timeout so a disconnected encoder
  fails the read instead of hanging the stepping loop.
- Accumulate turns across wraps. The sensor is absolute over one revolution
  only; a poll must never miss half a revolution. At 1 kHz that is safe past any
  speed this machine can reach, but assert it rather than assume: if two
  consecutive reads differ by more than half a revolution, that is a fault.
- New command: `ENCODER?` returning raw angle, accumulated counts and a
  magnitude/error status per encoder.

**Acceptance:** turn each motor by hand one full revolution; accumulated count
changes by 4096 ± a small tolerance, and does not jump at the wrap. Rotate
several turns each way and confirm it returns to where it started.

### Stage 2 — following-error monitoring, no correction

**Goal:** step loss becomes loud. Still open-loop motion.

- Keep the existing blocking move loop for now. Read the encoders every N steps
  inside it and compute following error.
- Halt the move if `|error| > following_error_limit` (default ~10 full steps =
  ~51 counts). Report the axis and the measured error.
- Report the peak and final following error in the move reply, and surface it
  through `gantry_controller.py` into the move result — mirror the shape of the
  `speed` report added to `_move_result` in `raspberry_gantry.py`.

**Acceptance:** run normal moves and confirm errors stay small. Then stall an
axis by hand and confirm it halts promptly and names the axis. This stage alone
is worth having even if stage 3 slips.

### Stage 3 — in-motion PID correction

**Goal:** the loop closes. Error is corrected continuously *during* the move.

1. **Replace the blocking step generator** with the timer-ISR design above.
   Prove it open-loop first: moves must be as accurate and as smooth as before,
   with trapezoidal accel intact, before any feedback is added. Do not skip this
   — a bug here looks exactly like a tuning problem later.
2. **Trajectory generator** producing target position per loop tick from the
   existing trapezoidal profile.
3. **PID**, per the specifics above, output summed into the step setpoint.
4. **Commands:** `SET XY PID <kp> <ki> <kd>`, `SET XY FOLLOW LIMIT <counts>`,
   `XY PID?` to read them back.
5. **Tuning support:** stream or buffer `(t, target, actual, error, output)` so
   gains can be tuned against data rather than by feel. The owner has been
   burned by judging behaviour by eye this session — give them numbers.

**Acceptance:** commanded moves land within a few encoder counts. Apply drag by
hand mid-move and watch it corrected in flight rather than at the end. Exceeding
the limit still halts. Compare repeatability against the Pi path using the
existing repeatability block.

---

## Safety rules — non-negotiable

- **E-Stop wins.** The stop path must halt the loop and the step generator
  immediately, and must not be delayed by serial handling.
- **Limits abort motion in firmware**, on the same board, without a round trip.
- **Never correct past the following-error limit.** A machine that keeps pushing
  into an obstruction with a tool head and glassware attached is the dangerous
  failure, not a stopped one.
- **Come up disabled.** After reset, drivers must be off until the host asks —
  the same rule the Z/pump board follows.
- **Position survives an abort.** Adopt the steps actually taken, as the Pi path
  and the Z axis both now do. An E-Stop must not cost the calibration.

---

## Files this touches

- `functions/esp 32 code/esp32 <new-id>/firmware/main.ino` — new
- `backend/app/services/gantry_controller.py` — new commands, error reporting
- `backend/app/models/gantry.py` — PID and follow-limit fields
- `hardware-map.json` — board, steppers, limits, encoders, enable pin
- `backend/tests/` — a test per stage; see below

## Testing

The suite is stdlib `unittest`, run with `ROBOT_GPIO_SIMULATE=1`. Firmware
cannot be unit-tested here, so test the **Pi side**: protocol formatting, reply
parsing, error propagation, and that a following-error fault becomes a failed
block rather than a silent pass.

Note the lesson from this session's tests: exercise the path the operator
actually presses. Testing `run_sequence` while `pickup()` was broken let a
NameError reach the machine with every test green. Cover the handler entry
points, not only the helpers.

## What only the machine can tell you

Everything below has to be checked on hardware, not reasoned about:

- Enable polarity on the new board
- Encoder counting direction versus motor step direction, per axis — a sign
  error here turns the PID into positive feedback and the axis will run away.
  **Verify this before enabling the integral term.**
- Magnet centring and air gap. A poorly centred magnet produces a smoothly
  varying error that looks exactly like a real reading.
- Achievable loop rate with serial traffic in flight

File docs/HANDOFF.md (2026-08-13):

# Handoff: backend rebuild, continuing on the Raspberry Pi

Written for the next AI agent (or human) picking this up **on the Pi, with the
robot attached**. The previous work was done on a Windows development machine
with no hardware, which is the single most important thing to know: several
things are implemented and unit-tested but have **never touched a real board**.

Read `docs/BACKEND_ARCHITECTURE_V2.md` first — it is the agreed design and the
defect-to-phase map. This file is the current state and what to do next.

---

## 0. Session update — first session actually on the Pi

Everything below this section was written without hardware. This section is
what changed once it ran on the real machine. **Robot power supply was
unplugged for all of it, so nothing could move.**

**Step 1 is done: the firmware compiles.** All five sketches build with the
`ID?` handler, including the standalone case with no `generated_identity.h`
(the `__has_include` guard works). Verified through the app's own
`build_firmware` path, so it is the same compile the backend performs:

| sketch | flash |
| --- | --- |
| `esp32 ttyUSB0` | 336,772 B (25%) |
| `esp32 ttyUSB1` | 315,140 B (24%) |
| `esp32 controller-ykkl80` | 315,472 B (24%) |
| `firmware/syringe-controller` (standalone) | 305,208 B (23%) |
| `firmware/z-axis-controller` (standalone) | 315,472 B (24%) |

**The identity handshake now works end to end on real hardware.** This was the
largest "implemented but never run against a board" item. The Z controller was
flashed through the app's own path and asked who it was:

```
ID? -> {"controller_id":"controller-ykkl80","name":"Double Z axis and pumps",
        "fingerprint":"c91541999072da3d","protocol":1,
        "routines":["calibrate_z","move_z"]}
```

and preflight then made all three decisions correctly against that live board:

| situation | verdict | behaviour |
| --- | --- | --- |
| firmware matches | `ok` | flash skipped (7 s instead of ~30 s) |
| a pin changed in the Hardware Map | `needs_flash` | fingerprint mismatch detected |
| board reports a different controller id | `wrong_controller` | **refuses to flash** |

That last row is the fix for "flashing hit the wrong board": a board that says
it is something else is no longer overwritten.

What made it work is the missing link described in section 4a — `flash_firmware`
now actually writes `generated_identity.h`. Before, `render_identity_header`
existed but nothing called it, so every board answered with an empty identity.

**Both controllers now self-identify, with both plugged in at once.** The
syringe controller was connected later in the same session and brought up:

```
/dev/ttyUSB0  serial 58d72d4c…  ->  controller-ykkl80  "Double Z axis and pumps"
/dev/ttyUSB1  serial 8012ef3b…  ->  controller-x83xnc  "7 syringe pump controller"
```

Preflight returns `ok` for both (no reflash), and the wrong-board case was
tested for real: aiming the syringe firmware at the Z board's port returns
`wrong_controller` and refuses. **This is the defect that used to overwrite a
working controller, now provably closed on hardware.** The syringe protocol
still works after reflashing (`SPEED`, `SET HEAD PINS` answer normally).

This required creating the workspace `esp32 controller-x83xnc`, which never
existed — section 3 notes the syringe controller had no workspace at all, which
is exactly why `plan_workflow_firmware` could not resolve it and downgraded it
to "externally programmed". The syringe firmware only lived at
`firmware/syringe-controller/`, outside any workspace. The syringe manifests
(`dispense`, `prime_syringes`, `7_syringe_dispenser_slow_and_good`) now declare
`builder_board_id: controller-x83xnc`; `dispense` previously claimed `ttyUSB1`,
which is the **Z** board.

**Section 2a is now confirmed with both boards present: the serials are
unique** (`58d72d4c…` vs `8012ef3b…`). The boards never shared a factory
serial; the duplication was purely the overwrite bug, now fixed.

**Access door interlock added (Pi GPIO 13).** A switch on the access door
gates *runs*, not all motion: a single block test with the door open still
works, because that is how the machine gets brought up and the operator is
standing there. Run all is refused, with a deliberate override for when it is
needed. Enforced backend-side via a run session, which also watches the door
for the run's duration and stops every actor through the safety controller if
it opens. Kept separate from the E-Stop latch on purpose - verified on hardware
that an E-Stop still latches while the door override is on. See section 4c.

**All 14 blocks are implemented.** `dispense` was still the generated
"not implemented" placeholder; it and the 7-syringe preset now share one input
mapping. The `ttyUSB0` board references on the Pi-driven blocks are retired -
see section 4c.

**The suite is green on the Pi: 74/74.** It was 8 failing (1 failure,
7 errors) purely from running on real hardware. See section 4a for what that
uncovered — one of them was a genuine production bug and one was a unit test
quietly driving the real gantry.

**Section 2's premise about USB serials is wrong — see section 2a.** The
conclusion (do not trust the serial as recorded) still holds, but for a
different and *fixable* reason. Read 2a before acting on section 2.

---

## 1. The aim

A local-first, modular lab-robot platform. A Raspberry Pi coordinates; a
browser UI edits hardware maps and workflows; ESP32 controllers run low-level
motor/sensor code.

The rebuild exists because the orchestration layer was unreliable in three ways
the operator hit constantly:

1. **Workflows ran in an unpredictable order.** Blocks fired in the order the
   wires happened to be drawn, joins fired early, `if` ran both branches, loops
   never looped, and a failed block did not stop the run.
2. **E-Stop was advisory.** Five services each owned a private stop flag,
   `/rearm` cleared two of them, and starting any new work silently cleared the
   latch. After a stop mid tool-change the machine claimed the head was empty
   while a tool was physically on it.
3. **Flashing hit the wrong board, or no board.** Two incompatible controller-ID
   namespaces meant a controller the plan could not resolve was silently
   downgraded to "externally programmed" and never flashed — the run then
   proceeded against whatever firmware happened to be on it.

The agreed decisions:

| Decision | Choice |
| --- | --- |
| Blast radius | Keep the hardware drivers, replace the orchestration above them |
| Firmware | Identity + fingerprint handshake and preflight now; code generation next |
| Parallel branches | Genuinely concurrent, gated by logical resource locks |
| Verification | Simulation-first; hardware was unavailable during development |

**Why the drivers were kept:** `raspberry_gantry.py`, `gantry_controller.py`,
`hybrid_z_axis.py` and `syringe_controller.py` are ~180 KB of hardware-tuned
code (CoreXY step timing, trapezoidal accel, fast-touch/backoff/slow-touch limit
probing, partial-travel adoption after an aborted move). That behaviour was
tuned against the physical machine and cannot be re-derived from a desk. Do not
rewrite them. Wrap them.

---

## 2. STOP: read this before flashing anything

**All three ESP32 workspaces record the same USB serial number.**

```
serial 58d72d4c84bcf01191f2167148e9de0f
    board_id=ttyUSB0             usb location=1-2
    board_id=ttyUSB1             usb location=3-2
    board_id=controller-ykkl80   usb location=(not recorded)
```

These are cheap CP2102N bridges that were never given unique serials at the
factory. This matters enormously, because `Esp32BuilderService._resolve_flash_port`
deliberately prefers the USB serial number over the port name, on the reasoning
that the serial identifies the physical chip. **On this hardware that reasoning
is false.** Every workspace resolves to whichever board currently enumerates
with that serial, so a flash aimed at the syringe controller can land on the
Z-axis controller.

This is very likely the concrete cause of "many problems with flashing".

Consequences for the design:

- USB serial number **cannot** be the controller identity here.
- The only fields that distinguish the two boards are the USB topology
  locations (`1-2` vs `3-2`), which are stable only while the cables stay in
  the same physical ports.
- Therefore **firmware-reported identity (`ID?`) is the only trustworthy
  identity**, which is exactly what has been built — but it has a bootstrap
  problem: a board must be flashed once before it can say who it is.

**Safe bootstrap procedure, to be done by hand the first time:**

1. Unplug both ESP32s.
2. Plug in **one** board only.
3. Confirm exactly one port enumerates: `ls -l /dev/ttyUSB*`.
4. Flash it with the workspace you intend for that physical board.
5. Verify: `python3 -c "import serial,time; p=serial.Serial('/dev/ttyUSB0',115200,timeout=2); time.sleep(2); p.write(b'ID?\n'); print(p.readline())"`
   — it must report the controller id you expect.
6. Unplug it, plug in the other, repeat.
7. Only then plug both in and let preflight verify them.

Do not skip this. Automating it before the boards can identify themselves means
guessing which board is which, and guessing wrong overwrites a working
controller.

Longer term, pick one: reprogram the CP2102N serials to be unique (Silicon Labs
`cp210x` utilities), or record the USB location as a tiebreaker in the Hardware
Map, or accept `ID?` as the sole authority after a one-time manual bring-up.
This is a judgement call for the project owner — **ask, do not decide it
silently.**

---

## 2a. Correction: the boards are NOT sharing one factory serial

Section 2 states that all three workspaces record the same USB serial because
"these are cheap CP2102N bridges that were never given unique serials at the
factory". **That inference is wrong.** The evidence:

`board.json` serials recorded over time, from git history:

| workspace | commit | date | serial | USB location |
| --- | --- | --- | --- | --- |
| `esp32 ttyUSB0` | aec21f8 | 2026-04-02 | `76ae3066…` | 3-1 |
| `esp32 ttyUSB0` | 4c86318 | 2026-06-26 | `b4ca1bab…` | 1-2 |
| `esp32 ttyUSB0` | d501505 | 2026-07-06 | `b4ca1bab…` | 3-2 |
| `esp32 ttyUSB0` | ac0d2b3 | 2026-07-19 | `b4ca1bab…` | 3-1 |
| `esp32 ttyUSB1` | 61623c5 | 2026-04-02 | `b4ca1bab…` | 1-2 |
| `esp32 ttyUSB1` | 57b8b07 | 2026-08-07 | `58d72d4c…` | 3-2 |

Three *distinct* serials appear (`76ae3066`, `b4ca1bab`, `58d72d4c`), and the
same serial appears at three different USB locations. Boards that shared a
factory serial would show one value everywhere; this shows the opposite.

**The real cause is that the workspace metadata is overwritten by whatever is
plugged in.** `Esp32BuilderService._ensure_board_workspace` (esp32_builder.py,
~line 725) writes:

```python
"serial_number": port.serial_number or existing_metadata.get("serial_number"),
```

The connected port's serial always wins. `_ensure_board_workspace` runs for
every connected port on `list_boards()` / `get_board()`, and the workspace is
chosen by port name (`/dev/ttyUSB1` → workspace `esp32 ttyUSB1`). So plugging
one board into a port stamps *that board's* serial onto *that port's*
workspace. All three currently read `58d72d4c…` because the Z board is the
only one connected and has visited all of those ports.

**What this changes:**

- The serial is probably a *usable* discriminator between the two physical
  boards. What is not usable is `board.json`'s record of it, because it is
  continuously overwritten.
- So the fix is not necessarily "abandon serial identity" — it may be "stop
  auto-overwriting recorded identity", i.e. treat `board.json` identity as an
  assertion made once, not a mirror of whatever is plugged in.
- `ID?` firmware identity is still the most robust answer and is still worth
  finishing. This just means the interim situation is less dire than section 2
  implies, and that the auto-stamp is a bug worth fixing regardless.

**Still an owner decision — not taken.** Confirm by plugging in each board
alone and recording its serial. What is *not* in doubt: with only one board
connected, every workspace resolves to it, so a flash aimed at the syringe
controller can still land on the Z controller. The section 2 bring-up
procedure remains the safe path until identity is settled.

---

## 3. The identity mess, exactly as it stands

Four different names exist for what appear to be two physical controllers.

**`hardware-map.json` boards:**

| id | usb_port | enabled | label |
| --- | --- | --- | --- |
| `controller-x83xnc` | `/dev/ttyUSB0` | **false** | 7 syringe pump controller |
| `ttyUSB1` | `/dev/ttyUSB1` | true | Double Z axis and pumps |

**Workspace directories** under `functions/esp 32 code/`:
`esp32 ttyUSB0`, `esp32 ttyUSB1`, `esp32 controller-ykkl80`.

**Function manifests** reference: `ttyUSB0`, `ttyUSB1`, `controller-ykkl80`.

Cross-referencing:

- `controller-ykkl80` is referenced by `calibrate_z` and `move_z` manifests and
  by `workflows/active-workflow.json`, but **no board with that id exists in the
  Hardware Map**. The Z motors are on board `ttyUSB1`.
- `controller-x83xnc` (the syringe controller, and the only board carrying the
  seven syringe-head devices) has **no workspace directory at all**, so
  `plan_workflow_firmware` cannot resolve it and warns it "has no firmware
  workspace; treating it as externally programmed". It is then excluded from the
  flash list.
- `dispense` declares `builder_board_id: "ttyUSB1"` but its devices sit on
  `ttyUSB0` — internally inconsistent, almost certainly wrong.

**Device placement** (19 devices):

- `raspberry-pi` (9): CoreXY A/B motors, X min/max, Y min limit switches, all
  four Z limit switches. The XY gantry and every limit switch is driven from Pi
  GPIO, not from an ESP32.
- `ttyUSB1` (2): `z-left-motor`, `z-right-motor`.
- `controller-x83xnc` (7): `syringe-head-a` … `syringe-head-g`, all disabled.
- unconnected (1): `y-max-limit-switch`, disabled.

Note the shape this implies: the Z axis is genuinely **cross-controller** —
motors on an ESP32, limit switches on Pi GPIO. That is the case the architecture
has to handle properly, and it is why `hybrid_z_axis.py` exists.

**On `function_assignments`:** there are 54 rows and **all 54 are identity
mappings** (`device_id == hardware_device_id`). The indirection currently buys
nothing while adding a second place that can go stale. Collapse it to
non-identity overrides only — but keep the field, since real overrides are the
point of Contract 1.

---

## 4. Where the work stands

### Done and unit-tested (162 tests pass)

**Phase 1a — one safety authority.** `backend/app/core/safety.py`.
A single `threading.Event` shared *by reference* with every motion driver, so a
hot stepping loop and an HTTP request consult the same boolean. The flag is set
before any actor is called, so a blocking serial write cannot delay an abort.
All five services self-register as `StoppableActor`s at import. New routes:
`GET /api/safety`, `POST /api/safety/stop|rearm|confirm-physical-state`.
`/api/emergency-stop` remains as a shim for the current frontend.

**Behaviour change to be aware of:** `rearm` now *refuses* while any physical
fact is unconfirmed. The frontend calls it before every block test, which is how
a pressed E-Stop used to get silently cleared.

**Phase 1b — physical state with certainty.** `backend/app/services/physical_state.py`.
Facts are three-valued (known / uncertain / absent) and written as **intent
before motion**, confirmed after. A stop mid-pickup leaves
`{held: 2, certainty: uncertain}` — the conservative belief — instead of the old
confident "empty". A stop while *idle* correctly leaves a settled tool known.
The legacy `toolhead-state.json` migrates in as uncertain. New file:
`physical-state.json` (gitignored).

**Phase 1c — thin simulation.** `backend/app/controllers/simulation.py`.
Answers `ID?`, `PING`, `STOP` honestly; acknowledges everything else without
modelling it. Deliberately *not* a machine simulator. Models three real board
states: correct firmware, pre-handshake firmware (does not recognise `ID?`), and
plugged-in-but-wedged. Simulated boards appear through `list_serial_ports()`.
Enable with `ROBOT_SIMULATED_CONTROLLERS`.

**Phase 2a — fingerprint and preflight.** `backend/app/controllers/{fingerprint,preflight,transport}.py`.
Fingerprint hashes routine set + resolved pin table + protocol + source
contents, canonicalised so collection order cannot change it. Five verdicts;
`WRONG_CONTROLLER` blocks the run rather than warning.

**Firmware `ID?` support.** `firmware/shared/controller_identity.h`, copied
beside all five sketches with an `ID?` branch added to each dispatch.
`__has_include`-guarded so the sketches still build standalone.

**Incidental fixes:** POSIX-only `/tmp` and `killpg` in the flash path (E-Stop
never killed an upload on Windows); `test_gpio_backend` was already failing
before any of this work because it read the mutable repo-root `gantry-state.json`
— state paths are now overridable via `ROBOT_GANTRY_STATE_FILE`,
`ROBOT_Z_GANTRY_STATE_FILE`, `ROBOT_PHYSICAL_STATE_FILE`.

### 4a. Fixed in the first on-Pi session

**Production bug — the GPIO loader could not fall back.**
`gpio_backend._load_rpi_gpio` caught only `ImportError`. The `rpi-lgpio` shim
executes real code at import against whatever `lgpio` it finds, so a version
skew raises `AttributeError` (`module 'lgpio' has no attribute
'SET_PULL_NONE'`) instead. That escaped the loader and crashed
`load_gpio_backend()` outright — meaning a `pip` upgrade on the Pi would take
the gantry down rather than fall back to the lgpio adapter, which is the entire
purpose of that function. Now catches `Exception` and reports the type.

**A unit test was driving the real gantry.** The three
`test_raspberry_gantry` routing tests call the full `calibrate_xy` / `move_xy`
path. On the Windows dev machine there was no GPIO library, so they silently
fell back to simulation and passed. On the Pi they configured real pins,
stepped real motors, and then failed on whatever the real limit switches read.
They only ever assert *routing* (`controller == "raspberry-pi"`), so they now
pin `ROBOT_GPIO_SIMULATE=1` explicitly. The fallback test additionally denies
`lgpio` (`sys.modules["lgpio"] = None`), since on the Pi lgpio really is
installed and it would otherwise fall through to real hardware instead of
simulation. **If the power supply had been connected, that suite run would
have moved the machine.**

**`test_reports_both_reasons_when_no_backend_is_available`** assumed both GPIO
libraries were absent — true on a laptop, false on the Pi. It now blocks both
imports explicitly.

**The three backend defects listed in Step 4 are done:**

- `test_function` hardcoded `ok=True`, so a handler returning `{"ok": false}`
  read as success and a workflow kept running past a failed block. It now
  honours the handler's own `ok`, surfacing `error`/`message` when false.
- `_load_handler_module` re-imported the handler on every call, so `cancel`
  ran against a *different module instance* than the run it meant to abort —
  any module-level state (open serial session, stop flag) was invisible to it.
  Modules are now cached, keyed on path + mtime so editing a handler still
  hot-reloads without a backend restart.
- `GET /api/functions` had write side effects (it regenerated manifests, which
  rewrites `hardware-map.json`) and the frontend polls it after every block
  run. Discovery is now read-only; the regeneration moved to
  `POST /api/functions/sync`. Blueprint edits still propagate because
  `esp32_builder` already calls `sync_generated_functions()` from its own
  save/delete/list endpoints.

Result: **74/74 tests pass on the Pi**, and the suite no longer touches
hardware (runtime 10s → 0.7s, which is itself the tell that it had been
stepping real motors).

### 4b. Identity handshake wired up (same session)

**`flash_firmware` now writes `generated_identity.h`.** This was the missing
link: `render_identity_header` existed but had no caller, so every flashed
board reported an empty identity and preflight could only ever say "cannot
verify → flash it". `_prepare_sketch_dir` now stamps the header into the sketch
immediately before compiling, so identity ships with the firmware.

**`Esp32BuilderService.build_firmware_bundle(board_id, workspace_dir, metadata)`**
assembles what should be on a controller: routine ids from the manifests whose
`builder_board_id` is that board, the resolved pin table for the devices the
Hardware Map places on it, and hashes of the firmware sources. Changing any of
those changes the fingerprint, so the board stops matching and gets reflashed;
a rebuild that changes nothing keeps matching and is skipped.

**Controller name added** (was requested): the header now also defines
`ROBOT_CONTROLLER_NAME` and `ID?` returns a `name` field, so a board can say
"I am the Double Z axis and pumps controller" rather than only an opaque id.
The name is deliberately **excluded from the fingerprint** — renaming a
controller in the Hardware Map must not make every board look stale. Names and
ids are escaped for the C string literal, so a stray quote in the Hardware Map
cannot emit a header that fails to compile.

**`flash_firmware(board_id, skip_if_current=True)`** asks the board first:
`ok` → skip, `wrong_controller` → refuse with an error, anything else → flash.
`preflight_board(board_id)` exposes the verdict on its own for a caller that
wants to decide for itself. The default is still `skip_if_current=False`, so
nothing silently changed behaviour for existing callers — **the run path still
needs to opt in** (see next steps).

**Workspace identity is no longer overwritten by whatever is plugged in.**
`_ensure_board_workspace` used to prefer the connected port's serial over the
recorded one; it now only fills identity in when it is genuinely unknown. This
is the section 2a bug. Note the corollary: `board.json` files written *before*
this fix may still hold a wrong serial, so treat existing recorded serials as
suspect until each board has been seen alone.

8 tests added (`tests/test_identity_flash_path.py`), **82/82 pass**.

### 4c. Access door, block audit and the ttyUSB0 cleanup (same session)

**Access door.** `backend/app/services/access_door.py` reads GPIO 13 (closed
switch = closed door, so the pin reads high when open - confirmed against the
real switch). `GET /api/safety` now carries `access_door` and `run_allowed`;
`POST /api/safety/access-door/override` toggles the override, which is not
persisted. `POST /api/safety/run-session/start|end` is what a run calls: start
is refused while the door blocks a run or the stop is latched, and it watches
the door until end. The watch runs only during a run - polling it while idle
would stop the machine every time someone reached in, which is exactly when
block testing is wanted.

**Skip ESP32 flashing is gone.** Flashing is decided by asking the board
whether its firmware is already correct, so the manual toggle had no purpose;
the toolbar slot is now the door override.

**Firmware prep also runs for a single block test**, not just Run all, so a
controller missing the routine a block calls gets flashed without having to run
the whole workflow.

**Handshake no longer resets the board.** Opening the port the ordinary way
toggles DTR/RTS and reset the ESP32, forcing a 2 s boot wait per board per run.
The port is now opened without asserting those lines and drained until quiet.
Firmware prep for both controllers: ~15 s -> ~3.8 s. Note the trap found on the
way: a *fixed short* settle reads the board's boot banner as the answer to
`ID?`, which parses as "no identity" and reflashes a good controller. Drain
until quiet, never for a fixed interval.

**Block audit.** All 14 blocks implemented, none stubbed. Seven carried
`builder_board_id: ttyUSB0` while the Hardware Map placed their hardware on
`raspberry-pi`. Corrected; `calibrate_xy`'s blueprint moved to
`functions/esp 32 code/retired-blueprints/` because a blueprint's workspace is
what sets `builder_board_id`, so editing the generated manifest never stuck.

**Controller ids are now stable.** The Hardware Map named boards after ports
(`ttyUSB0`/`ttyUSB1`) while the firmware reported `controller-ykkl80` /
`controller-x83xnc`, so preflight refused every flash as `wrong_controller`.
The boards were renamed to the ids the firmware reports and each records its
USB serial. Port-derived ids cannot work here - the ports renumbered twice in
one session.

### 4d. The run engine — the control-flow blocks now actually work

**The headline: `if`, `if_else`, `while`, `for` and `loop_over` had never been
implemented.** Every one returned `status: "simulated"` and handed the
condition string back untouched. There was no condition evaluator anywhere in
the codebase and no iteration counter. The browser's runner then walked the
edge array depth-first and followed *every* outgoing edge regardless of which
handle it came from — so `if` ran both branches, a loop body ran exactly once,
a fan-in fired once per incoming branch, and error edges were taken during
healthy runs. They looked like blocks that worked because nothing ever
contradicted them.

What now exists, all in `backend/app/engine/`:

- **`plan.py`** — compiles the graph to a validated `ExecutionPlan` before
  anything moves. Finds start nodes, join barriers, loop-back edges; rejects
  cycles that are not loops and loops with no body; warns about blocks nothing
  reaches and error paths that can never run.
- **`conditions.py`** — evaluates the condition strings. An AST walk over a
  small allowed grammar, **deliberately not `eval`**: a workflow file is data
  that can be hand-edited or copied between machines, and on a box wired to
  motors "open this workflow" must not mean "run this code". Calls, imports and
  comprehensions are refused *by name* instead of quietly evaluating false. An
  empty condition is false — that stops a `while` rather than spinning it.
  Accepts `$in.x`, `$blocks.calibrate_z.calibrated`, `$run.iteration`, n8n-style
  `{{ }}` wrapping, and JavaScript spellings (`true`/`null`).
- **`scheduler.py`** — walks the plan. Edges are tri-state (waiting / live /
  dead) and *dead propagates downstream*; that is what lets a join proceed when
  a branch feeding it was never taken, and what stops it firing per-branch.
  Loops are re-entrant scopes whose body edges reset each iteration, with a step
  guard so a runaway loop ends. `PlanRunner` is steppable from outside.
- **`journal.py`** — one append-only JSONL file per run: blocks, results,
  decisions, outcome. Pruned to the newest 200. `run-journal/` is gitignored.

**The split that matters:** the engine decides, the browser executes. Hardware
resolution, firmware flashing and the safety interlocks already live in the
frontend and work, so they stayed there. Only the decisions moved. The browser
opens a run, is handed what is due, executes it, reports back, and is told what
that made ready — `POST /api/engine/runs`, then `/results` per block.

Two behaviours preserved on purpose: RESUME after an E-Stop still skips blocks
that already finished (re-running a move is a physical action, not a wasted
call), and retries stay in the browser since that is where execution happens.

One deliberate behaviour change: **blocks nothing reaches no longer run.** The
old walk treated every parentless block as a root and ran it, which is a
surprising way to move a gantry. They now surface as a notice. `Test_1.json`
has 12 such blocks; `active-workflow.json` has none.

Not done: **resource locks.** Blocks that come due together are still executed
one at a time. That is safe but not parallel — locks (`gantry.xy`, `z.left`,
`syringe.head_b`, `controller:<id>:serial`, acquired in a fixed global order)
are what would make overlapping a Z move and a dispense safe. The serialising
loop in `runWorkflowThroughEngine` is commented with exactly this.

### Implemented but NEVER run against hardware

Treat all of this as unverified:

- The `ID?` handler in the five `.ino` files. **There was no C++ toolchain or
  arduino-cli on the development machine, so the firmware was never compiled.**
  The header uses only `Serial.print`, an `inline` function and `__has_include`
  (GCC 5+; the ESP32 toolchain is well past that), so it is expected to build —
  but that is reasoning, not evidence. **Compile it first, before anything else.**
- `SerialTransport` — the 2-second post-open settle and the `readline` loop were
  written against the datasheet behaviour of ESP32 auto-reset, not observed.
- The whole preflight path against real boards.

### Not started

- **Phase 2b:** unify the ID namespaces, migrate workspaces and
  `hardware-map.json`, wire preflight into the flash path.
- ~~**Phase 3:** the run engine.~~ **Mostly done — see 4d.** Remaining:
  resource locks for real parallelism, and SSE instead of the browser driving
  the loop.
- **Phase 4:** function packages and partial-hardware degradation.
- **Phase 5:** frontend becomes a viewer over the run API.

---

## 5. What to do next, in order

### Step 1 — verify the firmware compiles (DONE — see section 0)

All five sketches compile. Nothing here is blocked any more. The command below
is kept because it is still the way to re-check after editing the header; note
the sketch folder name must match the `.ino` name, which is why going through
`esp32_builder.build_firmware(board_id)` is easier than calling arduino-cli by
hand on `firmware/`:

```bash
cd backend && ./.venv/bin/python -c \
  "import sys; sys.path.insert(0,'.'); \
   from app.services.esp32_builder import esp32_builder_service as s; \
   print(s.build_firmware('ttyUSB1').ok)"
```

The remaining unverified half is a **real board answering `ID?`**, which is
gated on the identity decision below.

### Step 1 (original, for reference) — verify the firmware compiles

```bash
cd "/home/robot/robot control/Robot-Code"
.arduino-cli/../tools/arduino-cli/arduino-cli compile \
  --config-file .arduino-cli/arduino-cli.yaml \
  --fqbn esp32:esp32:esp32 \
  "functions/esp 32 code/esp32 ttyUSB1/firmware"
```

If `controller_identity.h` does not compile, fix it there and in the other four
copies. If it does, do the manual one-board-at-a-time bring-up from section 2
and confirm a real board answers `ID?`.

### Step 1b — what is left on identity (do this next)

The mechanism works; what remains is data and wiring:

1. **Make the run path opt into `skip_if_current=True`.** Today the frontend
   still calls flash unconditionally, so runs reflash every board even though
   the board can now say it is already correct. This is the change that
   actually delivers "stop reflashing everything".
2. **Bring the syringe controller up the same way.** It was not connected this
   session. Do it alone on the bus (section 2 procedure), flash it, confirm
   `ID?` reports `controller-x83xnc`. After that both boards self-identify and
   the USB-serial ambiguity stops mattering for good.
3. **Reconcile the ids** — see the mismatch below, which the bundle builder
   makes visible: asking for board `controller-ykkl80` yields `pins: []`
   because the Hardware Map puts the Z motors on board `ttyUSB1`, while
   `calibrate_z`/`move_z` declare `builder_board_id: controller-ykkl80`. The
   fingerprint is therefore computed over an empty pin table for that board.
   Not wrong yet — nothing depends on those pins being in the fingerprint —
   but it means a Z pin change would *not* trigger a reflash. Fix it as part
   of the namespace migration.
4. Likewise `dispense` declares `builder_board_id: ttyUSB1` (the Z board) while
   its devices sit on the syringe board, so board `ttyUSB1`'s bundle currently
   claims a `dispense` routine. Same migration.

### Step 2 — decide the identity strategy with the owner

Section 2 lists the three options. This changes the migration, so settle it
before writing the migration.

### Step 3 — Phase 2b, the migration

**Back up `hardware-map.json` and `workflows/*.json` before touching them.**
This is real machine configuration, not test data.

The migration must:

- give every controller one stable id, used by the Hardware Map, the workspace
  directory, and the manifests
- rewrite `devices[].board_id`, `builder_board_id`, and the saved workflows to
  match, keeping Contract 10 (missing references stay visible, nothing silently
  deleted)
- add `schema_version` to `hardware-map.json` (Contract 13 requires it; it
  currently only has `version: 1`)
- reconcile `controller-x83xnc` (no workspace) and `controller-ykkl80` (no
  board), which are probably a missing workspace and a stale board id
  respectively — **confirm with the owner which physical board is which** rather
  than inferring it
- resolve the duplicated firmware trees: `firmware/z-axis-controller/main.ino`
  and `functions/esp 32 code/esp32 controller-ykkl80/firmware/main.ino` were
  byte-identical before the `ID?` patch, and `firmware/syringe-controller/`
  mirrors a workspace too. The workspace copies are what actually get flashed.
  Deleting a tree is the owner's call.

Then wire `preflight_controller` into the run path so runs stop reflashing
everything, and have `flash_firmware` write `generated_identity.h` (from
`render_identity_header`) into the sketch before compiling.

### Step 4 — Phase 3, the run engine — **MOSTLY DONE, see section 4d**

Design is in `BACKEND_ARCHITECTURE_V2.md` §5–§6 and §8. Summary: compile the
graph to a validated `ExecutionPlan` before anything moves; a node is ready when
every *activated* incoming edge has delivered; control blocks activate only the
edge they chose; fan-in is a real join barrier; loops are re-entrant scopes with
an iteration guard; every node acquires its logical resources
(`gantry.xy`, `z.left`, `syringe.head_b`, `controller:<id>:serial`) in a fixed
global order so two branches wanting the gantry serialise while a Z move and a
dispense genuinely overlap.

~~Two backend defects to fix while you are in there:~~ **All three are done —
see section 4a.** (`test_function` `ok=True`, `_load_handler_module`
re-importing, and `GET /api/functions` write side effects.)

One follow-up they created: the frontend still calls `GET /api/functions`
expecting the sync side effect (it refreshes the block catalog after every
successful run so placed blocks pick up regenerated manifests). That still
works, because the catalog is re-read — but if a *blueprint* changed and the
manifests need regenerating, the frontend should now call
`POST /api/functions/sync` instead. Worth doing when Phase 5 touches the
frontend.

---

## 6. Practical: running things on the Pi

```bash
cd "/home/robot/robot control/Robot-Code"

./start-all.sh            # backend + frontend
./start-backend.sh        # backend only, uvicorn on 0.0.0.0:8000

# tests (stdlib unittest, no pytest needed)
cd backend && ./.venv/bin/python -m unittest discover -s tests -t .
```

Frontend `http://<pi>:5173`, backend `http://<pi>:8000`, API docs `/docs`.

**Note:** run the suite with `ROBOT_GPIO_SIMULATE=1` on the Pi. It passes either
way now, but without it the GPIO-backed tests drive real pins. Two tests
(`test_gpio_backend`, `test_raspberry_gantry`) pin the flag *off* for
themselves because they specifically exercise the executed path against an
injected fake backend.

**Checking a workflow without running it** — validates the graph, reports loops
with no body, unreachable blocks, joins that cannot complete. Side-effect free:

```bash
curl -s -X POST localhost:8000/api/engine/plan \
     -H 'Content-Type: application/json' \
     --data-binary @workflows/active-workflow.json | python3 -m json.tool
```

**Reading back what a run did:** `GET /api/engine/runs/history`, then
`GET /api/engine/runs/<run_id>/journal`. Files live in `run-journal/`
(gitignored, newest 200 kept); `ROBOT_RUN_JOURNAL_DIR` relocates them.

**Simulation on the Pi** (useful for testing preflight logic without unplugging
the real boards):

```bash
export ROBOT_SIMULATED_CONTROLLERS='[
  {"device":"SIM0","serial_number":"SIM-0001",
   "controller_id":"controller-x83xnc","fingerprint":"deadbeefdeadbeef",
   "routines":["dispense","prime"]}
]'
```

Simulated ports appear alongside real ones in `list_serial_ports()`. Unset it
before real runs so nothing resolves to a fake board.

**Check the safety latch** at any time:

```bash
curl -s localhost:8000/api/safety | python3 -m json.tool
```

---

## 7. Conventions and gotchas

- **Tests are stdlib `unittest`**, with `sys.path.insert(0, parents[1])` at the
  top of each file. There is a `.pytest_cache` but no pytest dependency.
- **Never let tests write repo-root state.** `gantry-state.json`,
  `z-gantry-state.json`, `physical-state.json` are live machine state. Use the
  `ROBOT_*_STATE_FILE` env overrides. A test that pollutes these makes the suite
  order-dependent — that bug already happened once.
- **Comments explain why, not what.** The existing code documents the hardware
  reasoning behind non-obvious choices (why the flag is set before the fan-out,
  why partial travel is adopted after an aborted move). Match that.
- **Contracts are binding.** `docs/ARCHITECTURE_CONTRACTS.md` is the governing
  document; `BACKEND_ARCHITECTURE_V2.md` is how it gets implemented. Contract 10
  in particular (missing references stay visible, never silently deleted) is
  easy to violate during a migration.
- The backend and frontend READMEs point to the governing architecture and
  backwards-compatibility contracts; keep those references current.
- Saved workflows embed a **frozen copy of every block definition** in
  `node.data.block`, which is why `workflows/Test_1.json` is 820 KB and why
  stale definitions leak into runs. Phase 5 replaces this with `block_id` +
  `version` resolved from the catalog at load.
- The gantry is **CoreXY**, not independent X/Y. `x-axis-motor` and
  `y-axis-motor` are compatibility names for CoreXY A and B.

---

## 8. Safety notes for whoever runs this next

- The E-Stop latch is now real and **will refuse to clear** while a physical
  fact is uncertain. That is intended. Clear it via
  `POST /api/safety/confirm-physical-state` then `POST /api/safety/rearm`, after
  physically checking the machine. Do not "fix" this by making rearm
  unconditional — that is the bug that was removed.
- After any stop mid tool-change, **look at the gantry before confirming.** The
  system deliberately does not guess.
- Calibration routines intentionally drive into limit switches (fast-touch,
  backoff, slow-touch). During normal motion a limit hit is a fault. Do not
  "fix" a calibration routine that appears to be crashing into a limit on
  purpose.
- First real-hardware run of anything in section 4 should be done with the
  motors powered down, watching the serial log, before letting it move.

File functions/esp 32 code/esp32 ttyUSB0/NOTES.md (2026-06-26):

# ESP32 Workspace Notes

- Port: `/dev/ttyUSB0`
- This folder stores the local source files and block-blueprint metadata for the connected CoreXY gantry ESP32.
- Editing these files in the UI updates the local workspace on the Pi.
- Use the Function Builder's Build + Flash action to compile and upload these sources to the board from the Pi.

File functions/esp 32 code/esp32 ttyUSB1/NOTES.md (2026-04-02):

# ESP32 Workspace Notes

- Port: `/dev/ttyUSB1`
- Display: `CP2102N USB to UART Bridge Controller`
- This folder stores the local source files and block blueprint metadata that the Pi UI edits.
- Use the Function Builder's Build + Flash action to compile and upload these sources to the board from the Pi.

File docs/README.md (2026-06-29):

# Documentation Index

Start with these files:

- `ARCHITECTURE_CONTRACTS.md`: stable contracts for workflow blocks, hardware maps, functions, firmware, and modules.
- `BACKWARDS_COMPATIBILITY.md`: versioning and migration policy.
- `LICENSE_POLICY.md`: software and future hardware licensing policy.
- `architecture.md`: current high-level architecture overview.

Templates:

- `templates/function-manifest.template.json`
- `templates/community-module.template.json`
- `templates/api-call-function.template.json`

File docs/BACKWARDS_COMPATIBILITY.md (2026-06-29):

# Backwards Compatibility Policy

## Version Promise

The current repository is pre-public-beta. The public baseline should be called `v0.1 beta`.

From `v0.1 beta` through the `v1.x` series:

- old saved workflows should load
- old hardware maps should load
- old function manifests should load or migrate
- old module manifests should load or show a clear broken-module placeholder
- old controller/firmware protocol references should either work or migrate

A future `v2` may intentionally fix architecture mistakes, but it should still provide migrations or clear compatibility tooling.

## Compatibility Target

Compatibility means:

- persisted files parse successfully
- missing references remain visible
- users get suggested fixes
- old expected behavior is covered by tests or migration fixtures
- migrations are deterministic and do not silently discard user work

Compatibility does not mean every old bug must stay. It means old projects should keep loading and have a documented path to the new behavior.

## Required Persistent Schema Fields

Before `v0.1 beta`, ensure these files have explicit versions:

- `hardware-map.json`: already has `version`
- workflow JSON: backend-normalized with `schema_version` and legacy `version`
- function manifests: backend model supports `schema_version`
- module manifests: must have `schema_version`
- firmware protocol descriptors: must have `schema_version`

Hardware map controller, device, and group `enabled` fields are additive. Older hardware maps without those fields load as enabled.

## Migration Rules

When a schema changes:

1. Keep the old parser path.
2. Add a migration from old shape to new shape.
3. Preserve unknown fields unless there is a documented reason not to.
4. Keep old IDs as aliases when possible.
5. Add or update fixture tests.
6. Update `docs/ARCHITECTURE_CONTRACTS.md` if the contract changes.

## Broken Reference Behavior

When a saved file points to something missing:

- render a broken block/device/module placeholder
- keep original IDs and metadata
- show what could not be resolved
- suggest repair actions
- avoid deleting the unresolved item on save unless the user explicitly removes it

Examples:

- workflow block references a missing advanced function
- function references a missing hardware device
- hardware device references a missing controller
- module references firmware that cannot be built
- API block references a missing secret name

Hardware maps without `function_assignments` load as having no function-to-hardware overrides. Missing function hardware is preserved by creating disabled, unconnected placeholders until the operator assigns the function requirement to a physical Hardware Map device.
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

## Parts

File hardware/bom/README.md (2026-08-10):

# Bill of Materials

- [Robot bill of materials](bill-of-materials.md): supplier links and quantities consolidated from purchasing discussions.

The BOM distinguishes installed or ordered parts from alternatives and unresolved items. Before a public release, reconcile repeated purchases against the assembled robot and remaining spares.

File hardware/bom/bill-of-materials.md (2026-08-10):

# Robot Bill of Materials

This inventory consolidates component and supplier links discussed in the direct-message thread with Thomas Vernay. Quantities reflect the latest explicit quantity found in that thread; they are purchasing quantities and may include spares. Links to papers, internal systems, job postings, and Slack messages are intentionally excluded.

## Main Robot

| Subsystem | Component | Part / option | Qty. | Supplier | Status / note |
|---|---|---:|---:|---|---|
| Sample handling | 24-deep-well plate | OptiWell 24-well deep-well plate | TBD | [MTC Bio](https://mtcbiotech.com/product/24-well-plates/) | Selected sample format |
| LAF enclosure | Laminar-flow cabinet | B0CN2HXRSL | 1 | [Amazon](https://www.amazon.de/dp/B0CN2HXRSL) | Selected from the compared cabinet options |
| Frame | V-slot aluminium profile | 20 x 20 mm, 750 mm | 1 | [MakerSupplies](https://makersupplies.dk/v-slot-profil-20x20-sort/) | Discussed replacement for an MGN rail |
| Frame | V-slot gantry plate | 20 mm system | 1 | [MakerSupplies](https://makersupplies.dk/v-slot-gantry-plade-20mm/) | Used with V-slot profile |
| Frame | Solid V-wheel kit | V-slot wheel kit | 4 | [MakerSupplies](https://makersupplies.dk/solid-v-wheel-kit/) | Used with V-slot profile |
| Linear motion | Lead screw and nut | T8, 8 x 800 mm, bronze nut | 2 | [Gleanntronics](https://www.gleanntronics.ie/product/t8-lead-screw-8mm-x-800mm-with-brass-nut/) | Double-Z drive |
| Linear motion | Lead screw and nut | T8, 8 x 600 mm, bronze nut | 4 | [Gleanntronics](https://www.gleanntronics.ie/product/t8-lead-screw-8mm-x-600mm-with-brass-nut/) | Earlier purchase list; verify installed lengths |
| Linear motion | GT2 timing belt | 10 mm wide, 5 m | 2 | [3D Eksperten](https://3deksperten.dk/products/2gt-timing-belt-w10mm-l5000mm) | Gantry transmission |
| Linear motion | Flexible shaft coupling | 5 x 8 mm | 2 | [3D Eksperten](https://3deksperten.dk/products/flexible-coupling-5x8mm) | Z-axis coupling |
| Linear motion | GT2 pulley | 20-tooth, 5 mm bore, 6 mm belt | 1 | [Amazon](https://www.amazon.de/dp/B0CWLHGPFV) | Latest pulley list |
| Linear motion | Timing pulley | Option 20-80T-8B-6 | 3 | [Amazon](https://www.amazon.de/dp/B0CQQZ4ZRR) | Exact option specified in DM |
| Linear motion | Ball bearings | 8 mm shielded miniature bearings | 2 packs | [Amazon](https://www.amazon.de/dp/B0FPGDCN8Z) | Verify bearing dimensions and pack count |
| Motion | NEMA 17 stepper motor | 2.5 A, 48 mm | 6 | [3D Eksperten](https://3deksperten.dk/products/nema17-stepper-motor-2-5a-48mm) | Four in first list and two in later list |
| Motion | High-torque stepper motor | SANMOTION SM2564C40B41, 24 V, 4 A, 2.5 Nm | 1 | [Mouser](https://www.mouser.dk/ProductDetail/SANMOTION/SM2564C40B41) | Confirmed ordered by Thomas |
| Motion control | Stepper driver | MKS TB67S109 with heatsink | 12+ | [3D Eksperten](https://3deksperten.dk/products/mks-tb67s109-stepper-driver-incl-big-heatsink-1) | Repeated orders; final installed/spare count must be reconciled |
| Motion control | Stepper driver | DRV8825 | 1 | [ArduinoTech](https://arduinotech.dk/shop/drv8825-stepper-motor-driver/) | Earlier pump prototype |
| Motion control | LED/actuator driver | DFRobot DRI0043 | 2 | [Mouser](https://www.mouser.dk/ProductDetail/DFRobot/DRI0043) | Verify final use |
| Control | Single-board computer | Raspberry Pi SC1111 | 1 | [Mouser](https://www.mouser.dk/ProductDetail/Raspberry-Pi/SC1111) | Earlier Pi order |
| Control | Single-board computer | Raspberry Pi SC1157 | 1 | [Mouser](https://www.mouser.dk/ProductDetail/Raspberry-Pi/SC1157) | Later Pi order; verify installed SKU |
| Control | Microcontroller board | ESP32-DevKitC-32E | 4 | [Mouser](https://www.mouser.dk/ProductDetail/Espressif-Systems/ESP32-DevKitC-32E) | Two listed in each of two orders |
| Control | STM32 development board | NUCLEO-G474RE | 1 | [Mouser](https://www.mouser.dk/ProductDetail/STMicroelectronics/NUCLEO-G474RE) | OD prototype |
| Power | 24 V power supply | Mean Well LRS-350N2-24 | 1 | [Mouser](https://www.mouser.dk/ProductDetail/MEAN-WELL/LRS-350N2-24) | Main 24 V supply |
| Safety / homing | Limit switch | Omron SS-5GL2 | 10 | [Mouser](https://www.mouser.dk/ProductDetail/Omron-Electronics/SS-5GL2) | Gantry and Z-axis limits |
| Wiring | Six-pin cable assembly | CABLE-PH06 | 12 | [DigiKey](https://www.digikey.dk/da/products/detail/analog-devices-inc-maxim-integrated/CABLE-PH06/9381902) | Order confirmed; quantity increased from 10 to 12 |
| Wiring | Ribbon cable | 10-pin jumper ribbon, 1.27/2.54 mm | 2 | [Amazon](https://www.amazon.de/dp/B09R42ZGQD) | Wiring harness material |
| Wiring | Micro-USB cable | USB-A to Micro-B, at least 2.5 m | 1 | [Amazon](https://www.amazon.de/dp/B0CSYKLKL2) | Verify purchased length |
| Wiring | Ribbon cable | 3M 8132-04-100 | 10 m | [DigiKey](https://www.digikey.dk/en/products/detail/3m/8132-04-100/1217834) | Verify conductor count |
| Thermal management | Heatsink | Assmann V2016B | 7 | [DigiKey](https://www.digikey.dk/en/products/detail/assmann-wsw-components/V2016B/3511426) | Driver cooling |
| Maintenance | Contact cleaner / lubricant | B0060K0VKI | 1 | [Amazon](https://www.amazon.de/dp/B0060K0VKI) | Anti-static, water-displacing spray |

## Seven-Syringe Pump

| Component | Part / option | Qty. | Supplier | Status / note |
|---|---:|---:|---|---|
| Long-stroke stepper actuator | 90 mm, 5 V | 1 | [ArduinoTech](https://arduinotech.dk/shop/precision-long-stroke-90mm-5v-stepper-motor/) | Early pump development |
| Disposable syringe | 0.3 mL | 1 pack | [Amazon](https://www.amazon.de/dp/B0CB9HCKWP) | Verify final syringe size |
| Check valve | Chemical-resistant membrane valve | 2 | [Amazon](https://www.amazon.de/dp/B0BS1DWB4Y) | Pump fluid path |
| Check valve | 4 mm inline valve | 2 | [Amazon](https://www.amazon.de/dp/B0FH62F5CY) | Pump fluid path |
| Hose connector set | Assorted barbed connectors | 1 | [Amazon](https://www.amazon.de/dp/B015EKYP7Y) | Pump plumbing |
| Irrigation hose coupling | VooGenzek 4 mm connector set | 1 pack | [Amazon](https://www.amazon.de/dp/B0CW36CB9L) | Latest pump list superseded the earlier quantity of two |
| Silicone tube | Transparent flexible transfer tube | 1 | [Amazon](https://www.amazon.de/dp/B0GJLD4PR7) | Pump plumbing |
| Flow distributor | Six-outlet adjustable air divider | 4 | [Amazon](https://www.amazon.de/dp/B08CKMSH6G) | Pump manifold candidate/order |
| Flow distributor | Six-way plastic divider | 3 | [Amazon](https://www.amazon.de/dp/B0BWMKZRWR) | Pump manifold candidate/order |
| Flow splitter | Aquarium hose splitter | 2 | [Amazon](https://www.amazon.de/dp/B0BTDJ4BQ8) | Pump manifold candidate/order |
| Unidentified pump item | B0CGNL26YZ | 1 | [Amazon](https://www.amazon.de/dp/B0CGNL26YZ) | Product title was not present in Slack export; verify |

## Tool Interface and Dispensing

| Component | Part / option | Qty. | Supplier | Status / note |
|---|---:|---:|---|---|
| Magnetic pogo connector | B0CVZWLNM2 | TBD | [Amazon](https://www.amazon.de/dp/B0CVZWLNM2) | Tool-connector candidate |
| Eight-pin magnetic pogo connector | B0D1KSC2V8 | TBD | [Amazon](https://www.amazon.de/dp/B0D1KSC2V8) | Tool-connector candidate |
| Magnetic pogo connector | Short-link item 03XizdiG | TBD | [Amazon](https://a.co/d/03XizdiG) | Later pogo option; verify exact model |
| Dosing needles | Assorted blunt needles | TBD | [Amazon](https://www.amazon.de/dp/B0DZ5M3WGZ) | Dispensing tool candidate |
| Curved dosing needle | 14 G blunt needle | TBD | [Amazon](https://www.amazon.de/dp/B0C4Y7828N) | Dispensing tool candidate |
| Servo | DFRobot SER0019 | 3 | [Mouser](https://www.mouser.dk/ProductDetail/DFRobot/SER0019) | Two in OD/electronics list and one later tool order |

## OD Prototypes

| Component | Part / option | Qty. | Supplier | Status / note |
|---|---:|---:|---|---|
| Photodiode | BPW34 / BPW-34-S | 50 | [Mouser](https://www.mouser.dk/ProductDetail/Vishay-Semiconductors/BPW34) | Ten in early prototype order and 40 in later order |
| Operational amplifier | LM358AM/NOPB | 10 | [Mouser](https://www.mouser.dk/ProductDetail/Texas-Instruments/LM358AM-NOPB) | First prototype |
| Operational amplifier | LM358N | 3 | [Mouser](https://www.mouser.dk/ProductDetail/Texas-Instruments/LM358N) | Early prototype order |
| Operational amplifier | MCP6002-I/P | 15 | [Mouser](https://www.mouser.dk/ProductDetail/Microchip-Technology/MCP6002-I-P) | Second prototype |
| Red LED | Broadcom HLMP-EG08-WZ000 | 30 | [Mouser](https://www.mouser.dk/ProductDetail/Broadcom-Avago/HLMP-EG08-WZ000) | Second prototype |
| LED driver | DFRobot SEN0527, TLC59711-based | 8 | [Mouser](https://www.mouser.dk/ProductDetail/DFRobot/SEN0527) | Six in early list plus two later boards |
| Ceramic capacitor | Vishay K104K15X7RF5WH5, 0.1 uF | 60 | [Mouser](https://www.mouser.dk/ProductDetail/Vishay-BC-Components/K104K15X7RF5WH5) | Amplifier filtering |
| Resistor | Stackpole RNF14FTD1M00, 1 Mohm | 45 | [Mouser](https://www.mouser.dk/ProductDetail/Stackpole-Electronics/RNF14FTD1M00) | Thirty in OD order and 15 later |
| Proto board / accessory | Adafruit 1455 | 2 | [Mouser](https://www.mouser.dk/ProductDetail/Adafruit/1455) | Verify function in final prototype |
| Prototype component | Soldered 000035 | 5 | [Soldered](https://soldered.com/product/000035/) | Verify description before publication |
| Enclosure | Hammond CSG12124 | 1 | [Mouser](https://www.mouser.dk/ProductDetail/Hammond-Manufacturing/CSG12124) | Electronics enclosure |

## Alternatives, Replacements, and Unresolved Items

These links were part of design or purchasing discussions but should not be presented as installed parts without checking the assembled robot.

| Component / discussion | Link | Status / note |
|---|---|---|
| Alternative laminar-flow cabinet | [Amazon B0FG2PKVLR](https://www.amazon.de/dp/B0FG2PKVLR) | Compared, not selected |
| Alternative laminar-flow cabinet | [Amazon B0F87KBT4R](https://www.amazon.de/dp/B0F87KBT4R) | Compared, not selected |
| MGN7C 600 mm rail | [Amazon B0C4P34WQL](https://www.amazon.de/dp/B0C4P34WQL) | Candidate before V-slot choice |
| Smooth pulley | [Amazon B097PSSXW2](https://www.amazon.de/dp/B097PSSXW2) | Candidate |
| MGN7H 750 mm rail | [Amazon B0GWPZTHYL](https://www.amazon.de/dp/B0GWPZTHYL) | Candidate |
| HGR20 800 mm rail set | [Amazon B0F9DPQTYD](https://www.amazon.de/dp/B0F9DPQTYD) | Candidate suggested by Thomas |
| MGN9H 750 mm rail | [Amazon B0BPH9H521](https://www.amazon.de/dp/B0BPH9H521) | Candidate suggested by Thomas |
| MGN7H 800 mm rail | [Amazon B0C4P1L4VC](https://www.amazon.de/dp/B0C4P1L4VC) | Candidate |
| Digital potentiometer | [ArduinoTech X9C103S](https://arduinotech.dk/shop/x9c103s-digital-potentiometer-module/) | Explicitly marked unnecessary for pump |
| JST-PH connector kit | [3D Eksperten](https://3deksperten.dk/products/jst-ph-connector-kit) | Unavailable when order was placed |
| Capacitor replacement | [Mouser 594-K104M10X7RF5UH5](https://www.mouser.dk/ProductDetail/Vishay-BC-Components/K104M10X7RF5UH5) | Substitute for unavailable K104M10X7RF5UL2; different lead spacing |
| Resistor replacement | [Mouser MBB02070C1503FC1](https://www.mouser.dk/ProductDetail/Vishay-BC-Components/MBB02070C1503FC1) | Substitute for unavailable MBB02070C1503FCT00 |
| Unidentified Amazon component | [B0CLRTJ3L2](https://www.amazon.de/dp/B0CLRTJ3L2) | Title absent from Slack export; verify |
| Unidentified Amazon component | [B0BDYQ2LP9](https://www.amazon.de/dp/B0BDYQ2LP9) | Title absent from Slack export; verify |
| Unidentified Amazon component | [B0BTY1D14C](https://www.amazon.de/dp/B0BTY1D14C) | Title absent from Slack export; verify |
| Unidentified Amazon component | [B0DSD9YF72](https://www.amazon.de/dp/B0DSD9YF72) | Quantity two in initial list; verify |
| Unidentified Amazon component | [B0BLS9P2S2](https://www.amazon.de/dp/B0BLS9P2S2) | Title absent from Slack export; verify |
| Unidentified Amazon component | [B096R4Q9Z3](https://www.amazon.de/dp/B096R4Q9Z3) | Title absent from Slack export; verify |
| Unidentified Amazon component | [B07H7FH8JX](https://www.amazon.de/dp/B07H7FH8JX) | Quantity three in July order; verify |
| Unidentified short-link component | [Amazon 0h570iG4](https://amzn.eu/d/0h570iG4) | Quantity two; verify before publication |

## Verification Notes

- Reconcile repeated order quantities against the installed robot and remaining spares, especially TB67S109 drivers, stepper motors, and OD components.
- Confirm which Raspberry Pi SKU is installed and retain only that row in the final public BOM.
- Resolve the unidentified Amazon items before treating this as a final manufacturing BOM.
- Supplier availability and prices change; manufacturer part numbers should remain the primary identifiers.

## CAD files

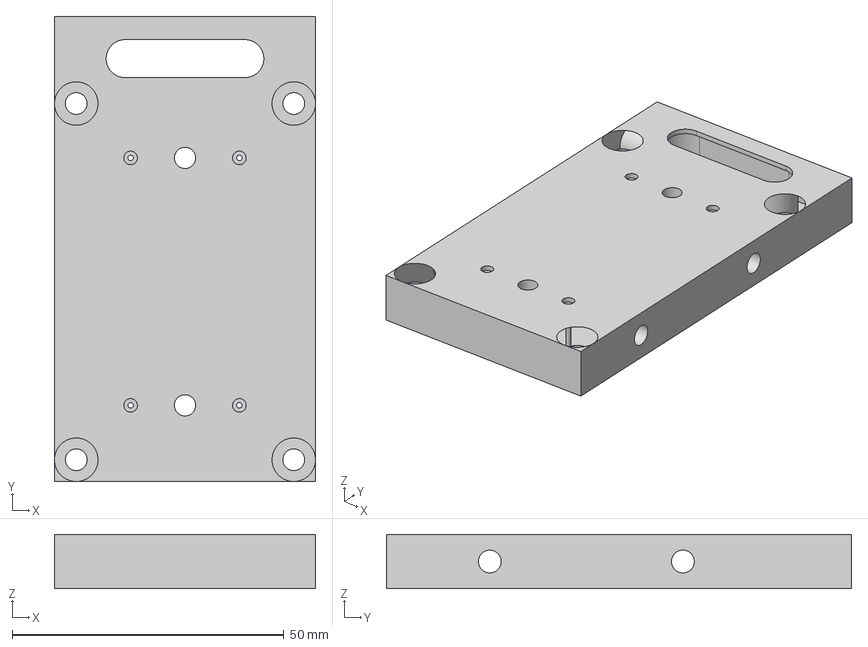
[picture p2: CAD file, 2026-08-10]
hardware/mechanical/frame-and-gantry/step/tool changer head.step
48.0 x 85.5 x 10.0 mm

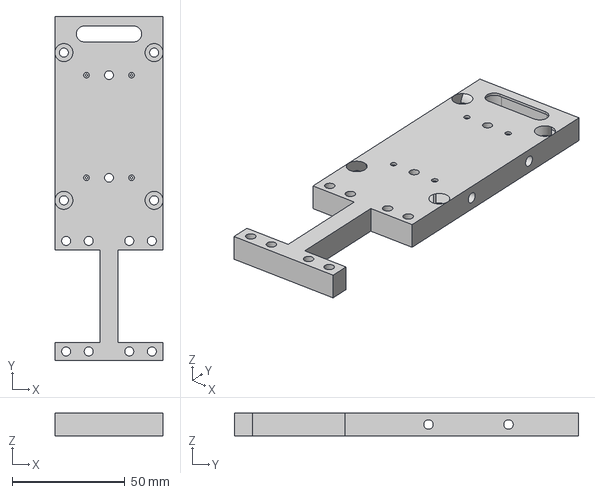
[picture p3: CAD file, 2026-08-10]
hardware/mechanical/gripper/step/gripper.step
48.0 x 152.5 x 10.0 mm

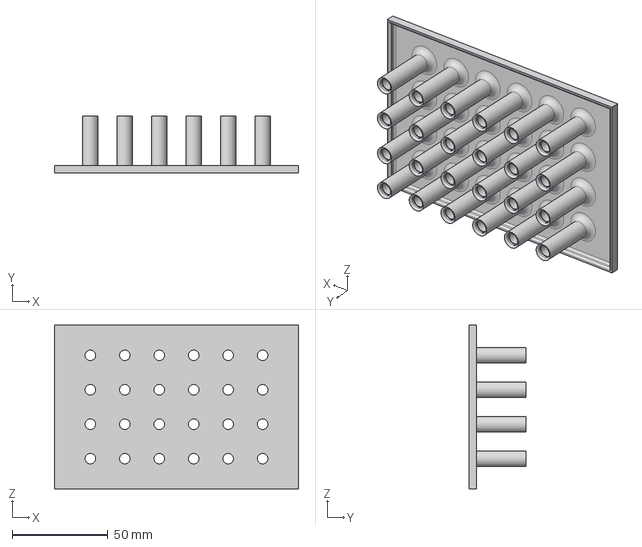
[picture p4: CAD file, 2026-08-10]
hardware/mechanical/optical-density/step/24 deep well led array.step
127.5 x 30.0 x 85.5 mm

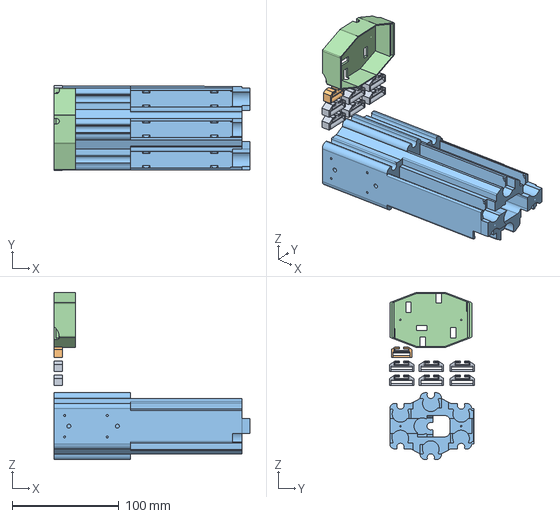
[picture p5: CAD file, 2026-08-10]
hardware/mechanical/seven-syringe-pump/step/syringe pump 3.step
184.0 x 80.0 x 157.2 mm

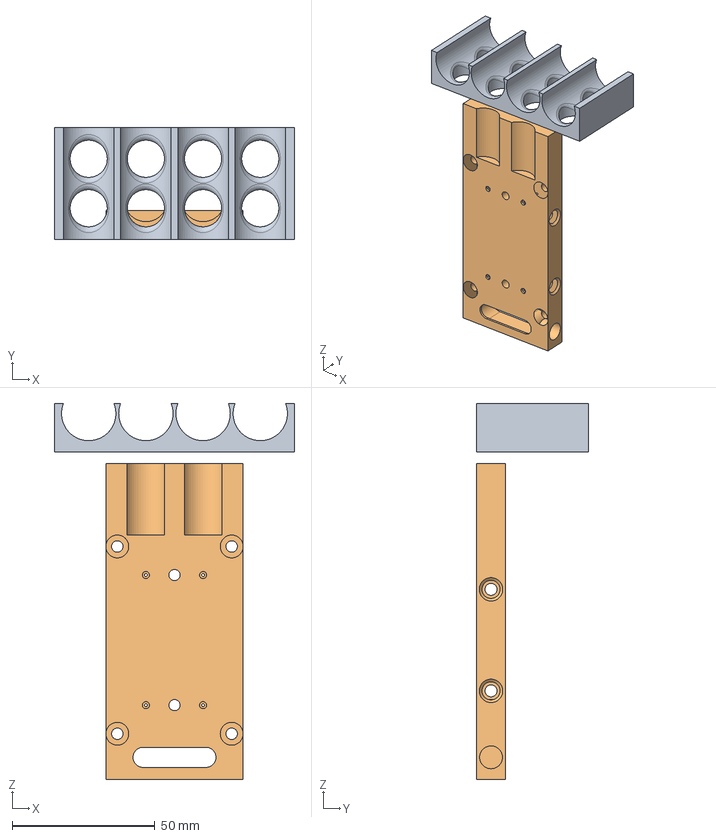
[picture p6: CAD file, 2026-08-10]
hardware/mechanical/suction-pump/step/suction pump head.step
84.0 x 39.0 x 131.5 mm

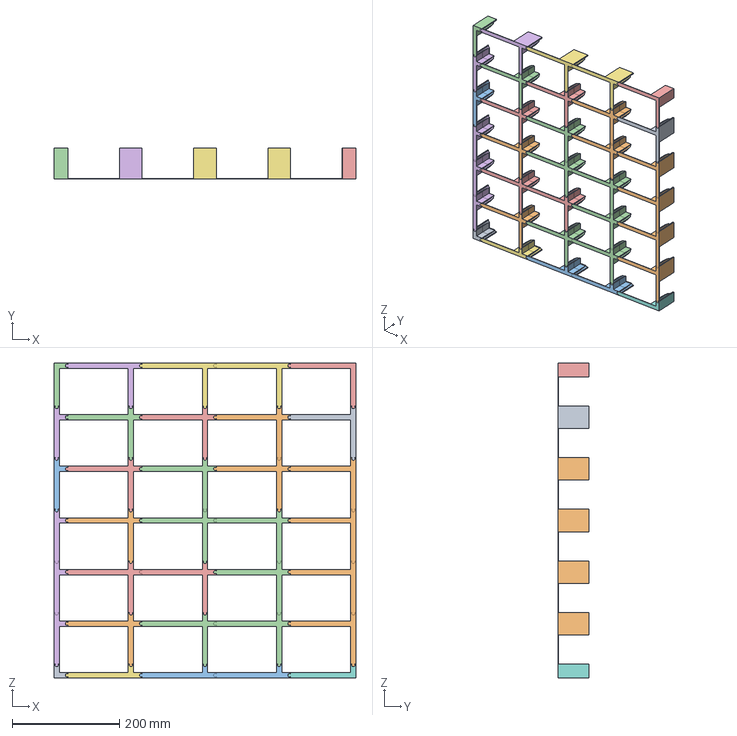
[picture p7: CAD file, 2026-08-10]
hardware/mechanical/tray-handling/step/Tray spacers.step
562.0 x 57.0 x 586.0 mm

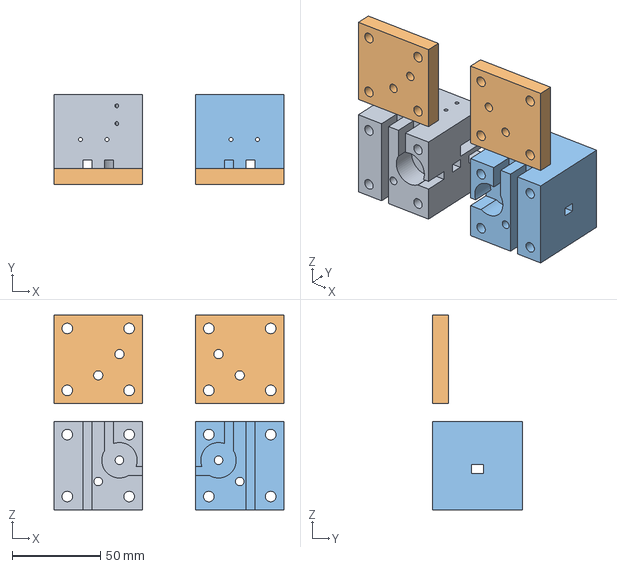
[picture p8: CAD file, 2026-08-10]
hardware/mechanical/frame-and-gantry/step/midrail support.step
130.0 x 51.0 x 110.0 mm

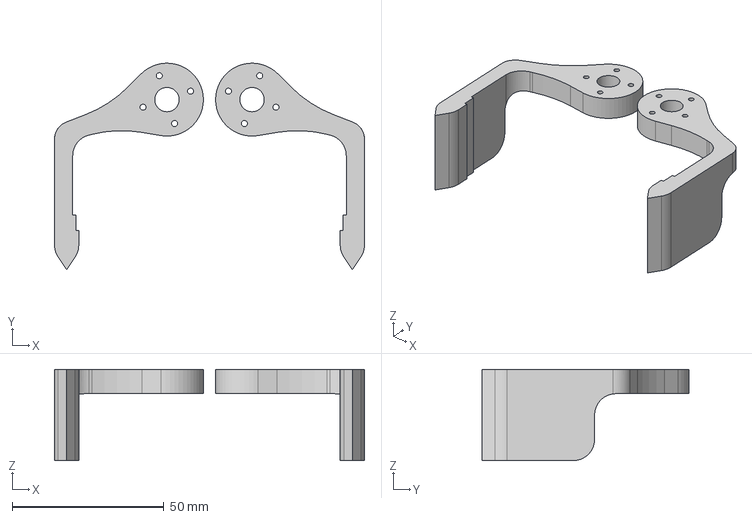
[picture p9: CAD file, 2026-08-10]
hardware/mechanical/gripper/step/Gripper Hands.step
102.0 x 68.0 x 30.0 mm

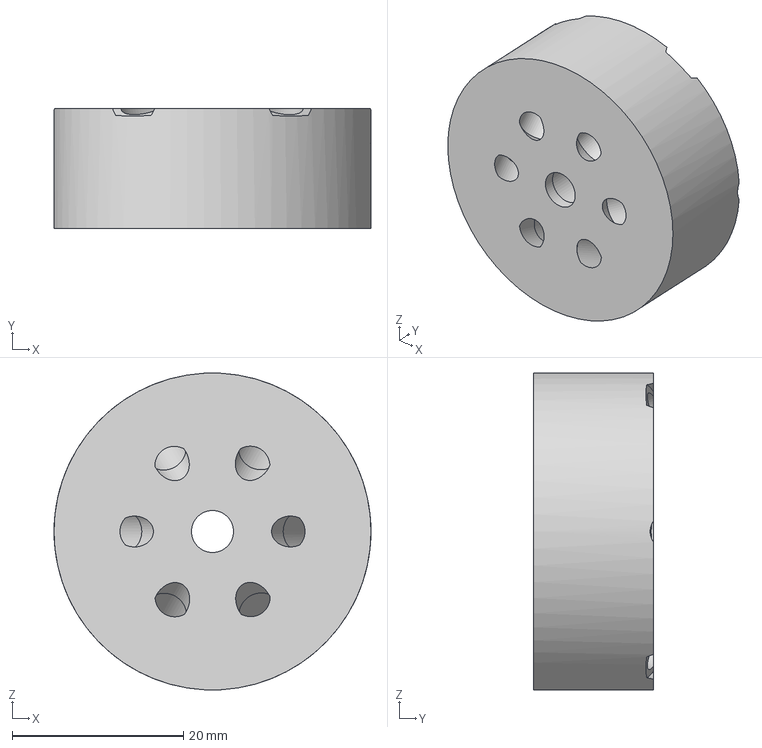
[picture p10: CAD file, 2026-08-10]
hardware/mechanical/seven-syringe-pump/step/7syringe holder 2.step
37.0 x 14.0 x 37.0 mm

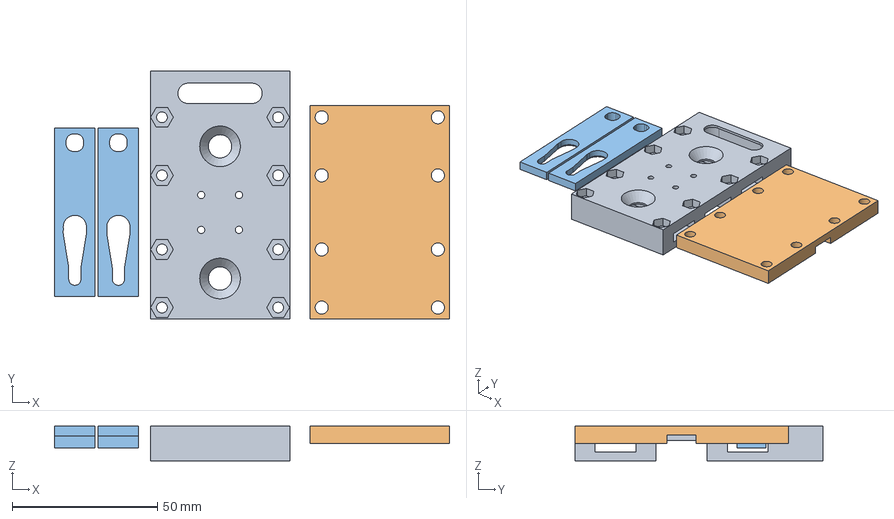
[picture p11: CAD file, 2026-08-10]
hardware/mechanical/frame-and-gantry/step/tool change neck.step
136.0 x 85.5 x 12.0 mm

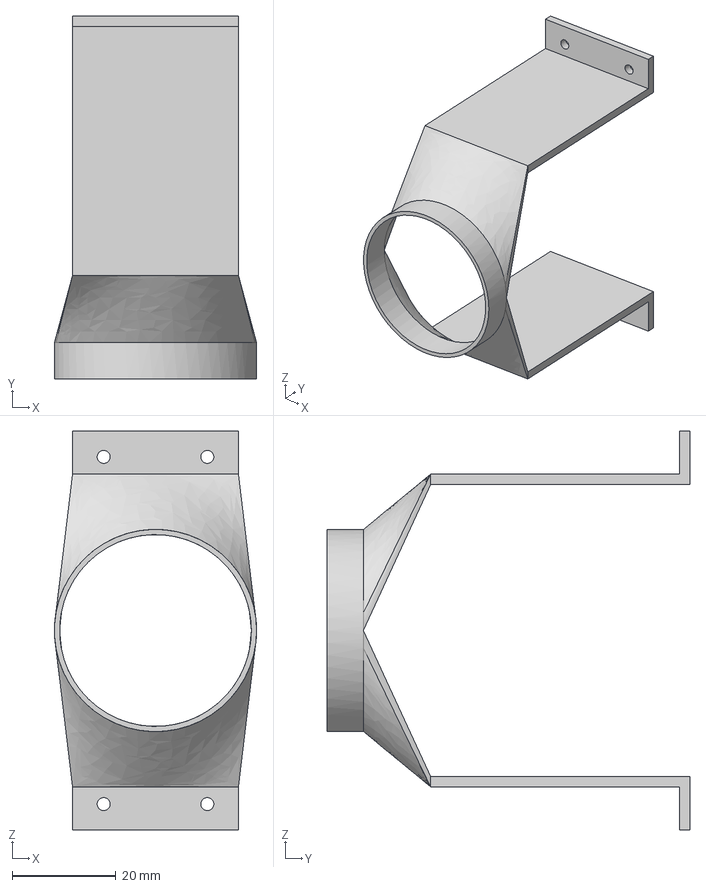
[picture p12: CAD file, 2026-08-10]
hardware/mechanical/seven-syringe-pump/step/syring support.step
39.0 x 70.0 x 77.0 mm

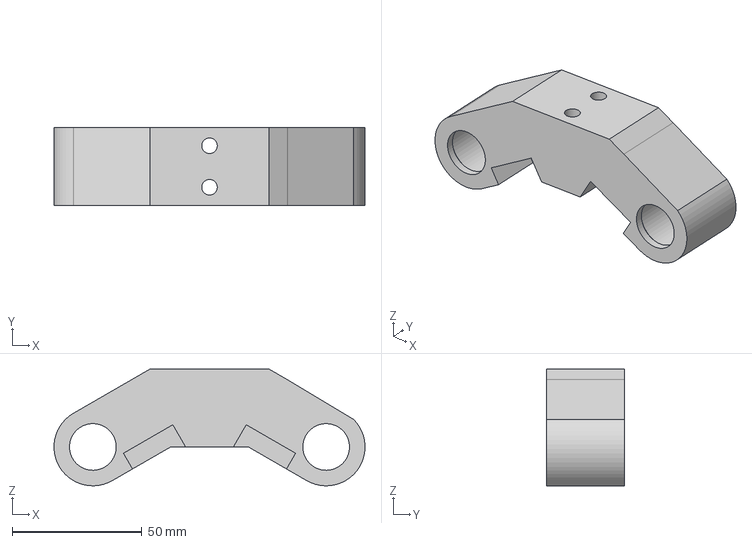
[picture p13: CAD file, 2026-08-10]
hardware/mechanical/frame-and-gantry/step/Lead screw double support.step
120.0 x 30.0 x 45.0 mm

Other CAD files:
hardware/electronics/source/Schematic of 7 syringe pump.f3z
hardware/electronics/source/Schematic of the pump and double z axis.f3z
hardware/mechanical/frame-and-gantry/source/Lead scrrw double support.f3d
hardware/mechanical/frame-and-gantry/source/midrail support.f3d
hardware/mechanical/frame-and-gantry/source/tool change neck.f3d
hardware/mechanical/frame-and-gantry/source/tool change support.f3d
hardware/mechanical/frame-and-gantry/source/tool changer head.f3d
hardware/mechanical/gripper/source/Gripper Hands.f3d
hardware/mechanical/gripper/source/gripper.f3z
hardware/mechanical/optical-density/source/24 deep well led array.f3d
hardware/mechanical/seven-syringe-pump/source/7syringe holder 2.f3z
hardware/mechanical/seven-syringe-pump/source/syring support.f3d
hardware/mechanical/seven-syringe-pump/source/syringe pump.f3z
hardware/mechanical/suction-pump/source/suction pump head.f3z
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

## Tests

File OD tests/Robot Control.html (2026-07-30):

Save map

E-STOP

raspberry

Raspberry PiUSB host + GPIO/I2C2 controllers, 5 direct devicessource

device

Y Max Limit SwitchPosition / limit switchunconnecteddisabled

device

CoreXY A MotorStepper motor6 pins

device

CoreXY B MotorStepper motor6 pins

device

X Min Limit SwitchPosition / limit switch1 pin

device

X Max Limit SwitchPosition / limit switch1 pin

device

Y Min Limit SwitchPosition / limit switch1 pin

controller

7 syringe pump controller/dev/ttyUSB07 devicesdisabled

device

Syringe Head AStepper motor6 pinsdisabled

device

Syringe Head BStepper motor6 pinsdisabled

device

Syringe Head CStepper motor6 pinsdisabled

device

Syringe Head DStepper motor6 pinsdisabled

device

Syringe Head EStepper motor6 pinsdisabled

device

Syringe Head FStepper motor6 pinsdisabled

device

Syringe Head GStepper motor6 pinsdisabled

controller

Double Z axis and pumps/dev/ttyUSB06 devicesoffline

device

Z Left MotorStepper motor6 pins

device

Z Right MotorStepper motor6 pins

device

Z Left Min Limit SwitchPosition / limit switch1 pin

device

Z Left Max Limit SwitchPosition / limit switch1 pin

device

Z Right Min Limit SwitchPosition / limit switch1 pin

device

Z Right Max Limit SwitchPosition / limit switch1 pin

React Flow (https://reactflow.dev/)

Press enter or space to select a node. You can then use the arrow keys to move the node around. Press delete to remove it and escape to cancel.

Press enter or space to select an edge. You can then press delete to remove it or escape to cancel.

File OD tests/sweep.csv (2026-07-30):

led_index | duty | main_adc | ch0_pb11 | ch1_pb12 | ch2_pc2 | ch3_pc3 | ch4_pc5 | ch5_pa7 | ch6_pb15 | ch7_pb14 | ch8_pa9 | ch9_pa8 | ch10_pb2 | ch11_pb1 | ch12_pc4 | ch13_pb13 | ch14_pc1 | ch15_pc0 | ch16_pa6 | ch17_pa5 | ch18_pa4 | ch19_pb0 | ch20_off | ch21_off | ch22_pa0 | ch23_pa1
0 | 0 | 5.00 | 5.00 | 5.60 | 5.60 | 5.80 | 7.00 | 5.20 | 6.40 | 5.00 | 3.60 | 4.20 | 6.40 | 7.00 | 5.60 | 5.60 | 5.80 | 9.00 | 5.20 | 6.80 | 7.80 | 8.20 | 0.00 | 0.00 | 6.00 | 6.60
0 | 512 | 47.00 | 47.00 | 12.40 | 6.60 | 5.60 | 13.20 | 7.40 | 6.80 | 4.60 | 5.00 | 4.80 | 6.20 | 6.60 | 6.20 | 5.60 | 5.40 | 9.40 | 5.40 | 7.20 | 8.00 | 8.20 | 0.00 | 0.00 | 5.60 | 6.20
0 | 1024 | 96.80 | 96.80 | 21.80 | 8.60 | 6.00 | 21.40 | 11.00 | 7.60 | 5.60 | 6.00 | 5.40 | 6.20 | 7.20 | 7.20 | 6.40 | 5.60 | 10.40 | 5.20 | 7.20 | 7.80 | 8.60 | 0.00 | 0.00 | 6.00 | 6.80
0 | 1536 | 146.40 | 146.40 | 31.40 | 9.40 | 5.80 | 29.20 | 13.80 | 8.20 | 5.00 | 8.00 | 6.60 | 7.00 | 7.20 | 7.20 | 6.40 | 6.60 | 10.20 | 5.20 | 7.20 | 8.00 | 9.20 | 0.00 | 0.00 | 6.20 | 6.40
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

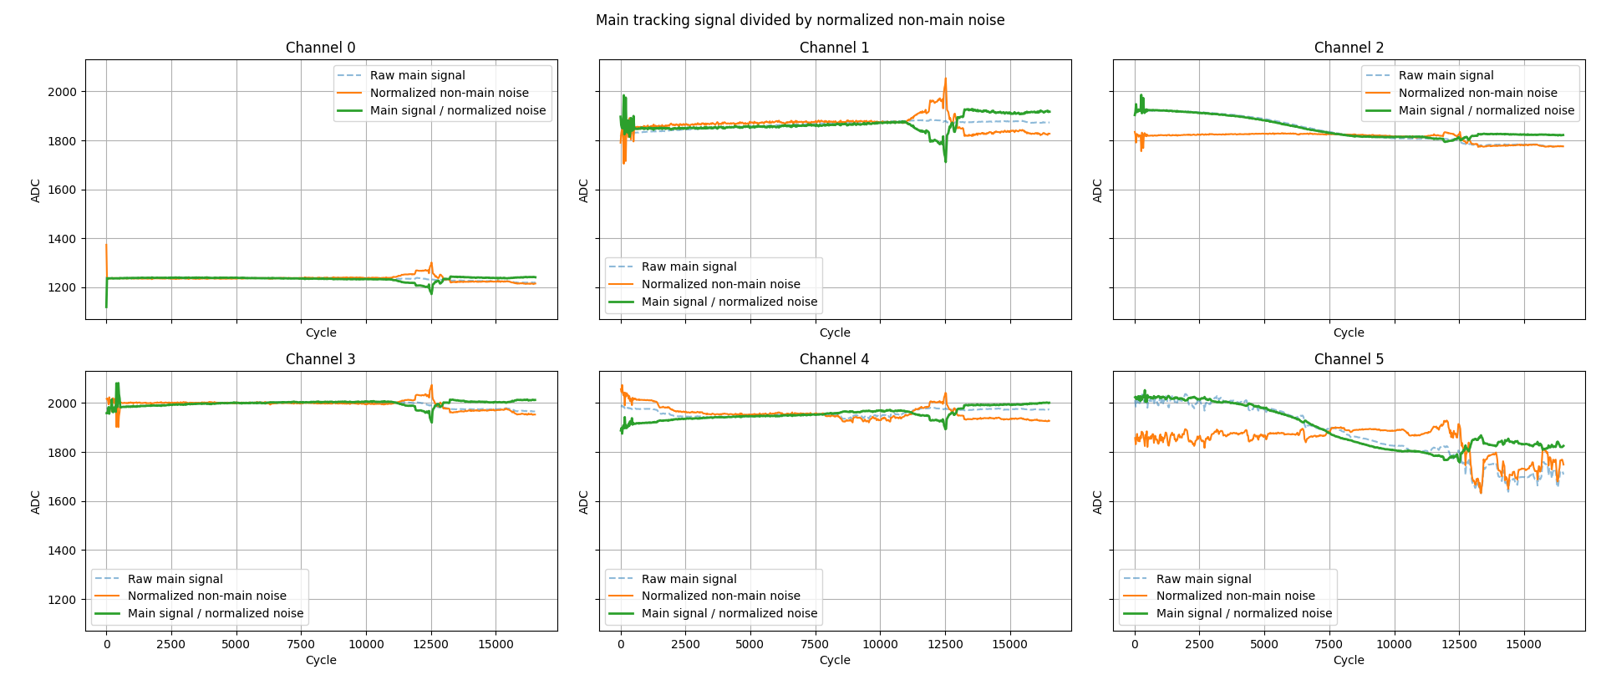
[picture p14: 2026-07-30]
OD tests/Figure_4.png

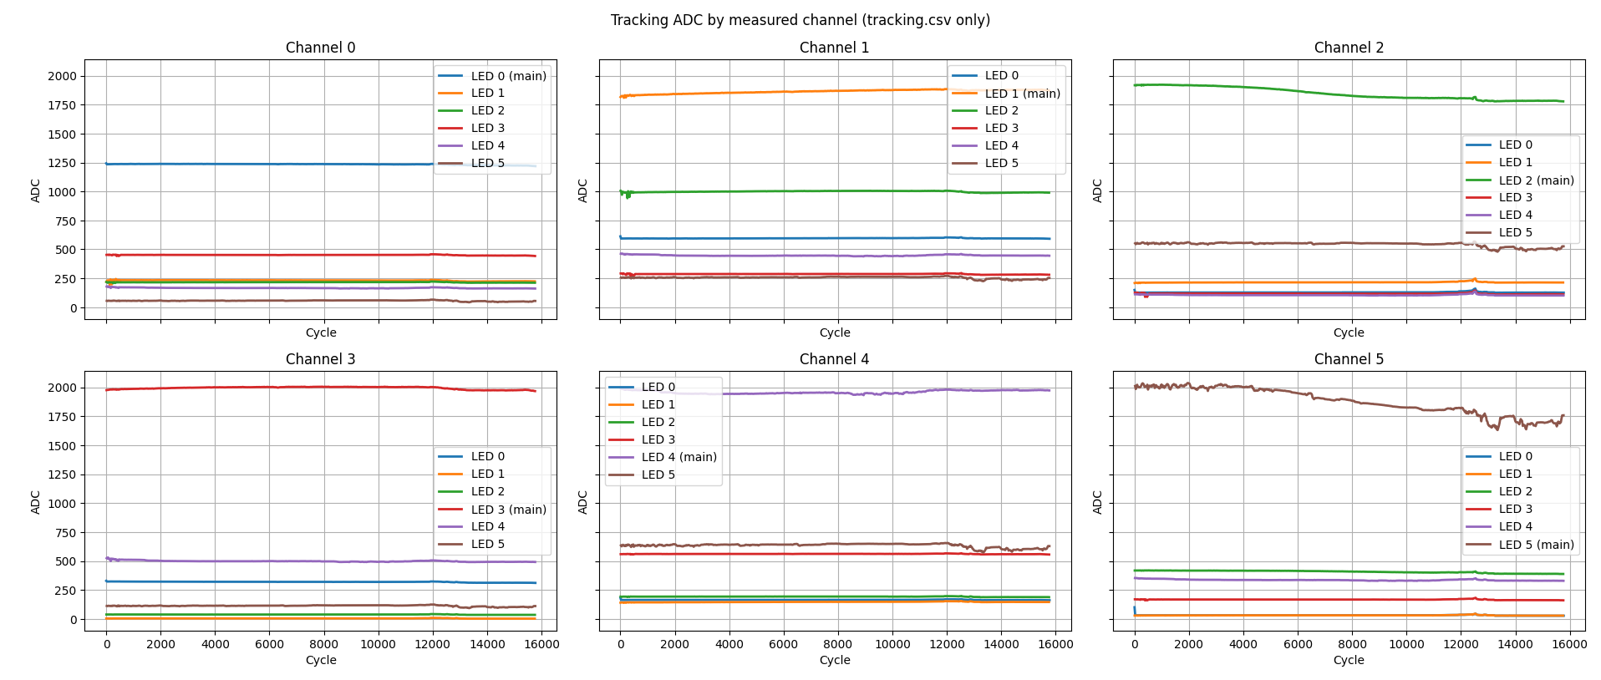
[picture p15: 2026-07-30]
OD tests/Figure_3.png

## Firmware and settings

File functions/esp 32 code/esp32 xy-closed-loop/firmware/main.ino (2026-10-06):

#include <Arduino.h>
#include "controller_identity.h"
#include <Preferences.h>
// Included up here, not beside the encoder code, because the Arduino builder
// inserts function prototypes right after the first include block - and the
// encoder functions take a TwoWire&.
#include <Wire.h>

// Forward declaration only. The Arduino build auto-generates function
// prototypes right after this include block, before EncoderChannel's full
// definition further down - a function taking "EncoderChannel &" only needs
// the type to be known, not complete, for that generated prototype to compile.
struct EncoderChannel;

// Non-volatile storage so the X calibration (and last known position) survive
// the ESP32 auto-reset that happens each time the host opens the serial port.
Preferences gantryPrefs;

const int DEFAULT_STEPS_PER_REVOLUTION = 800;
const int STEP_PULSE_WIDTH_US = 20;
const float DEFAULT_XY_STEPS_PER_CM = 100.0f;
const float Z_STEPS_PER_CM = 100.0f;
const float DEFAULT_X_WORKSPACE_CM = 115.0f;
const float DEFAULT_Y_WORKSPACE_CM = 60.0f;
const float DEFAULT_Z_WORKSPACE_CM = 60.0f;
const float NEAR_LIMIT_CALIBRATION_CM = 3.0f;
const int SLOW_PROBE_RPM_FLOOR = 25;
const int DEFAULT_MAX_PROBE_ROTATIONS = 120;
const long XY_PROBE_BACKOFF_STEPS = 200;
const long XY_SLOW_PROBE_EXTRA_STEPS = 300;

// X-min homing refinement: after the fast touch, back off one full rotation
// (reversed direction) and re-approach the switch slowly for a repeatable home.
const int XY_SLOW_HOMING_RPM = 10;

// Safety buffer kept between the usable workspace and every limit switch, so
// moves to 0 or to max stop short of the switches instead of tripping them. Set
// per calibration and persisted, because every later move maps user coordinates
// through it: changing it without re-reading it would silently shift the origin.
const float DEFAULT_XY_LIMIT_BUFFER_CM = 0.5f;
// How far the gantry parks clear of the Y-min switch, in motor rotations,
// while X calibrates. Rotations convert to steps with nothing but the
// steps-per-rotation setting, so the distance is exact even before any
// steps-per-cm has been measured. Sweeping X with the carriage still resting on
// the Y switch loads the frame against its stop, so calibration steps off first.
const float DEFAULT_X_CALIBRATION_Y_ROTATIONS = 1.6f;
// Freeing a limit switch that is already pressed when calibration starts reuses
// the homing back-off distance of one full motor rotation, which is already
// known to release a switch. The nudge repeats up to this many rotations and
// re-checks after each one, so it stops the moment the switch frees and a switch
// with a longer throw still clears.
const int XY_LIMIT_NUDGE_MAX_ROTATIONS = 4;

// CoreXY X travel directions (dir-pin level applied to BOTH A and B motors).
// These reflect the current driver wiring; flip the two values together if the
// X axis is ever rewired.
const int XY_DIR_TOWARD_X_MIN = HIGH;
const int XY_DIR_TOWARD_X_MAX = LOW;

struct AxisChannel {
  int stepPin;
  int dirPin;
  int minLimitPin;
  int maxLimitPin;
  long currentSteps;
  float trackLengthCm;
};

AxisChannel xAxis = {16, 17, 21, 22, 0, DEFAULT_X_WORKSPACE_CM};
AxisChannel yAxis = {18, 19, 23, 25, 0, DEFAULT_Y_WORKSPACE_CM};
AxisChannel zLeftAxis = {32, 33, 12, 13, 0, DEFAULT_Z_WORKSPACE_CM};
AxisChannel zRightAxis = {32, 33, 12, 13, 0, DEFAULT_Z_WORKSPACE_CM};

long currentXSteps = 0;
long currentYSteps = 0;
float xStepsPerCm = DEFAULT_XY_STEPS_PER_CM;
float yStepsPerCm = DEFAULT_XY_STEPS_PER_CM;
float xyLimitBufferCm = DEFAULT_XY_LIMIT_BUFFER_CM;
int stepsPerRevolution = DEFAULT_STEPS_PER_REVOLUTION;

int xyLimitSwitchMode = 4;
int zLimitSwitchMode = 4;
bool xyCalibrated = false;
bool zCalibrated = false;

// Y is not homed with a calibration probe. The first XY move after a calibration
// assumes the gantry is parked at Y = max; after that, Y is tracked like X.
bool yPositionKnown = false;

// Stepper driver ENABLE pins for the CoreXY A/B motors. -1 means "no enable pin
// wired" (driver is hardwired enabled), in which case all enable handling is a
// no-op. Most A4988/DRV8825/TMC carriers enable on a LOW level, so default to
// active-low.
int xEnablePin = -1;
int yEnablePin = -1;
bool xyMotorsEnableActiveLow = true;

// Bumped whenever the meaning of the saved calibration changes, so a record
// written by older firmware is discarded instead of misread. Version 1 never
// probed Y and saved it as "assumed parked at Y max"; version 2 homes Y against
// the Y-min switch, so a version 1 Y position is wrong by the length of the axis.
const int GANTRY_STATE_VERSION = 2;

void saveXCalibrationState() {
  gantryPrefs.begin("gantry", false);
  gantryPrefs.putInt("ver", GANTRY_STATE_VERSION);
  gantryPrefs.putBool("xyCal", xyCalibrated);
  gantryPrefs.putFloat("xStepsCm", xStepsPerCm);
  gantryPrefs.putFloat("xTrackCm", xAxis.trackLengthCm);
  gantryPrefs.putLong("xPos", currentXSteps);
  gantryPrefs.putBool("yKnown", yPositionKnown);
  gantryPrefs.putLong("yPos", currentYSteps);
  gantryPrefs.putFloat("yTrackCm", yAxis.trackLengthCm);
  gantryPrefs.putFloat("bufCm", xyLimitBufferCm);
  gantryPrefs.end();
}

// Forgets any stored calibration, so the gantry reports itself uncalibrated and
// moves refuse rather than run against a position that is no longer true.
void invalidateXCalibrationState() {
  xyCalibrated = false;
  yPositionKnown = false;
  saveXCalibrationState();
}

void loadXCalibrationState() {
  gantryPrefs.begin("gantry", true);
  int storedVersion = gantryPrefs.getInt("ver", 1);
  bool usable = storedVersion == GANTRY_STATE_VERSION;
  if (usable) {
    // Steps-per-cm describes the belts, pulleys and microstepping, not where the
    // carriage happens to be, so it outlives an invalidated calibration. Keeping
    // it lets the next run convert cm to steps before X has been re-measured.
    xStepsPerCm = gantryPrefs.getFloat("xStepsCm", DEFAULT_XY_STEPS_PER_CM);
    yStepsPerCm = xStepsPerCm;
    // The buffer defines where user coordinate 0 sits, so a restored position is
    // only meaningful alongside the buffer it was recorded with.
    xyLimitBufferCm = gantryPrefs.getFloat("bufCm", DEFAULT_XY_LIMIT_BUFFER_CM);

    if (gantryPrefs.getBool("xyCal", false)) {
      xyCalibrated = true;
      xAxis.trackLengthCm = gantryPrefs.getFloat("xTrackCm", DEFAULT_X_WORKSPACE_CM);
      currentXSteps = gantryPrefs.getLong("xPos", 0);
      yAxis.trackLengthCm = gantryPrefs.getFloat("yTrackCm", DEFAULT_Y_WORKSPACE_CM);
      yPositionKnown = gantryPrefs.getBool("yKnown", false);
      currentYSteps = gantryPrefs.getLong("yPos", 0);
    }
  }
  gantryPrefs.end();

  if (!usable) {
    Serial.print("X CALIBRATION DISCARDED STALE STATE VERSION ");
    Serial.print(storedVersion);
    Serial.print(" EXPECTED ");
    Serial.println(GANTRY_STATE_VERSION);
  }

  Serial.print("X CALIBRATION RESTORED ");
  Serial.print(xyCalibrated ? 1 : 0);
  Serial.print(" STEPS_PER_CM ");
  Serial.print(xStepsPerCm, 3);
  Serial.print(" TRACK_CM ");
  Serial.print(xAxis.trackLengthCm, 3);
  Serial.print(" X_POS_STEPS ");
  Serial.print(currentXSteps);
  Serial.print(" Y_KNOWN ");
  Serial.print(yPositionKnown ? 1 : 0);
  Serial.print(" Y_POS_STEPS ");
  Serial.println(currentYSteps);
}

int rpmForMoveProfile(const String &profile) {
  if (profile == "slow") {
    return 120;
  }
  if (profile == "fast") {
    return 420;
  }
  return 240;
}

int rpmForCalibrationProfile(const String &profile) {
  if (profile == "normal") {
    return 180;
  }
  return 100;
}

unsigned long stepIntervalMicrosForRPM(int rpm) {
  float stepsPerSecond = (rpm * stepsPerRevolution) / 60.0f;
  if (stepsPerSecond <= 0.0f) {
    stepsPerSecond = 1.0f;
  }

  unsigned long interval = (unsigned long)(1000000.0f / stepsPerSecond);
  unsigned long minimumInterval = (unsigned long)(STEP_PULSE_WIDTH_US * 2);
  if (interval < minimumInterval) {
    return minimumInterval;
  }

  return interval;
}

long rampIterationsForMotion(long totalIterations, int targetRpm, int accelerationRpmPerSecond) {
  if (totalIterations <= 2 || targetRpm <= 0 || accelerationRpmPerSecond <= 0) {
    return 0;
  }

  // Constant-acceleration ramp distance to reach the target speed: v^2 / (2a), in steps.
  float accelStepsPerSecond2 = (accelerationRpmPerSecond * (float)stepsPerRevolution) / 60.0f;
  float targetStepsPerSecond = (targetRpm * (float)stepsPerRevolution) / 60.0f;
  long rampIterations = (long)((targetStepsPerSecond * targetStepsPerSecond) / (2.0f * accelStepsPerSecond2));
  if (rampIterations < 1) {
    return 1;
  }

  long maxRamp = totalIterations / 2;
  return rampIterations > maxRamp ? maxRamp : rampIterations;
}

int rpmForTrapezoidIteration(long iteration, long totalIterations, int targetRpm, bool trapezoidalSpeed, int accelerationRpmPerSecond) {
  if (!trapezoidalSpeed) {
    return targetRpm;
  }

  long rampIterations = rampIterationsForMotion(totalIterations, targetRpm, accelerationRpmPerSecond);
  if (rampIterations <= 0) {
    return targetRpm;
  }

  long remaining = totalIterations - iteration - 1;
  long rampPosition = min(iteration + 1, remaining + 1);
  if (rampPosition > rampIterations) {
    rampPosition = rampIterations;
  }

  // Constant-acceleration speed after rampPosition steps: v = sqrt(2 * a * s).
  // On short moves rampIterations is clamped to half the distance, so the peak
  // becomes sqrt(a * distance) instead of the requested target speed - the move
  // accelerates to the midpoint and decelerates to 0, honoring the acceleration
  // value no matter how high the target speed is.
  float accelStepsPerSecond2 = (accelerationRpmPerSecond * (float)stepsPerRevolution) / 60.0f;
  float stepsPerSecond = sqrtf(2.0f * accelStepsPerSecond2 * (float)rampPosition);
  int nextRpm = (int)(((stepsPerSecond * 60.0f) / (float)stepsPerRevolution) + 0.5f);
  return max(10, min(targetRpm, nextRpm));
}

void prepareOutputPin(int pin) {
  if (pin < 0) {
    return;
  }

  pinMode(pin, OUTPUT);
  digitalWrite(pin, LOW);
}

void prepareLimitPin(int pin) {
  if (pin < 0) {
    return;
  }

  pinMode(pin, INPUT_PULLUP);
}

void writeEnablePin(int pin, bool enabled) {
  if (pin < 0) {
    return;
  }

  // When the driver enables on a LOW level, "enabled" must drive the pin LOW.
  bool driveHigh = enabled ? !xyMotorsEnableActiveLow : xyMotorsEnableActiveLow;
  digitalWrite(pin, driveHigh ? HIGH : LOW);
}

void setXYMotorsEnabled(bool enabled) {
  writeEnablePin(xEnablePin, enabled);
  writeEnablePin(yEnablePin, enabled);
}

void applyXYEnable(int nextAEnablePin, int nextBEnablePin, bool activeLow) {
  xEnablePin = nextAEnablePin;
  yEnablePin = nextBEnablePin;
  xyMotorsEnableActiveLow = activeLow;
  prepareOutputPin(xEnablePin);
  prepareOutputPin(yEnablePin);
  // Energize both CoreXY drivers immediately so single-axis moves still turn
  // both motors. A CoreXY axis requires both A and B drivers enabled.
  setXYMotorsEnabled(true);

  Serial.print("OK XY ENABLE ");
  Serial.print(xEnablePin);
  Serial.print(" ");
  Serial.print(yEnablePin);
  Serial.print(" ");
  Serial.println(xyMotorsEnableActiveLow ? 1 : 0);
}

bool isLimitActive(int pin) {
  return pin >= 0 && digitalRead(pin) == LOW;
}

bool consumeStopCommandIfPresent() {
  if (!Serial.available()) {
    return false;
  }

  String pending = Serial.readStringUntil('\n');
  pending.trim();
  pending.toUpperCase();
  if (pending == "STOP") {
    Serial.println("OK STOP");
    return true;
  }

  return false;
}

bool axisLimitActive(const AxisChannel &axis, bool positiveDirection, int limitMode) {
  if (positiveDirection) {
    return limitMode == 4 && isLimitActive(axis.maxLimitPin);
  }

  return isLimitActive(axis.minLimitPin);
}

bool cartesianLimitActiveForMove(long deltaX, long deltaY) {
  if (deltaX > 0 && xyLimitSwitchMode == 4 && isLimitActive(xAxis.maxLimitPin)) {
    return true;
  }
  if (deltaX < 0 && isLimitActive(xAxis.minLimitPin)) {
    return true;
  }
  if (deltaY > 0 && xyLimitSwitchMode == 4 && isLimitActive(yAxis.maxLimitPin)) {
    return true;
  }
  if (deltaY < 0 && isLimitActive(yAxis.minLimitPin)) {
    return true;
  }
  return false;
}

void applyAxisPins(AxisChannel &axis, int stepPin, int dirPin) {
  axis.stepPin = stepPin;
  axis.dirPin = dirPin;
  prepareOutputPin(axis.stepPin);
  prepareOutputPin(axis.dirPin);
}

void applyAxisLimits(AxisChannel &axis, int minLimitPin, int maxLimitPin, int limitMode) {
  axis.minLimitPin = minLimitPin;
  axis.maxLimitPin = maxLimitPin;
  prepareLimitPin(axis.minLimitPin);
  if (limitMode == 4) {
    prepareLimitPin(axis.maxLimitPin);
  }
}


// ---------------------------------------------------------------------------
// Closed-loop XY: AS5600 magnetic encoders on the A and B motor shafts, read
// over I2C.
//
// One encoder per physical motor - "A" and "B" here, matching xAxis/yAxis
// above which despite their names pulse the A and B motors respectively (see
// runCoreXYCartesianMove). Each encoder maps 1:1 to one motor, so the two PID
// loops are independent: no CoreXY transform inside the control loop, only
// when converting a cartesian target into A/B deltas, exactly as every move
// already does.
//
// AS5600 is 12-bit (4096 counts/revolution). At 800 steps/revolution that is
// 5.12 counts per full step, so single-step loss is still visible.
//
// Every AS5600 answers at the same fixed I2C address (0x36), so the two
// cannot share a bus. Each gets one of the ESP32's two hardware I2C
// controllers instead: encoder A on Wire, encoder B on Wire1, each with its
// own SDA/SCL pair. No multiplexer chip, and one encoder's bus fault cannot
// stall the other's.
//
// Correction is applied inside the existing, proven CoreXY stepping loop
// rather than a separate high-rate timer ISR. This is a deliberate interim
// design: it makes the correction genuinely continuous - reconsidered every
// few step iterations throughout the move, not only at the end - using a step
// generator that is already tested and known to hold a straight CoreXY line.
// A fully independent 1kHz control task is the documented next step once this
// is proven on real hardware (see docs/CLOSED_LOOP_XY_PLAN.md); building that
// blind, with no encoder yet wired, is exactly the risk the plan warns against.
// ---------------------------------------------------------------------------

const int ENCODER_COUNTS_PER_REV = 4096;    // AS5600: 12-bit
const uint8_t AS5600_ADDRESS = 0x36;        // fixed; cannot be changed
// STATUS (0x0B) is immediately followed by RAW ANGLE (0x0C high, 0x0D low),
// so one 3-byte read returns the magnet state and the angle together.
const uint8_t AS5600_REG_STATUS = 0x0B;
const uint8_t AS5600_STATUS_MD = 0x20;      // magnet detected
const uint8_t AS5600_STATUS_ML = 0x10;      // magnet too weak (too far away)
const uint8_t AS5600_STATUS_MH = 0x08;      // magnet too strong (too close)
// Fast mode. The AS5600 also allows 1 MHz, but the pull-ups on the common
// breakout boards are sized for 400 kHz; raise it only after checking the
// edges on a scope.
const uint32_t AS5600_I2C_HZ = 400000;
// A missing or wedged encoder must fail a read, not hang the stepping loop.
const uint16_t AS5600_I2C_TIMEOUT_MS = 2;

struct EncoderChannel {
  TwoWire *bus = nullptr;
  int sdaPin = -1;
  int sclPin = -1;
  uint16_t lastRaw = 0;          // last raw 12-bit angle read
  long turns = 0;                // accumulated counts across revolutions
  bool primed = false;           // false until the first read establishes lastRaw
  bool faulted = false;          // set on a bus error, a magnet fault or a missed wrap
  uint8_t lastStatus = 0;        // AS5600 STATUS from the last read
};

EncoderChannel encoderA;   // on the A motor shaft (xAxis.stepPin/dirPin), I2C bus 0
EncoderChannel encoderB;   // on the B motor shaft (yAxis.stepPin/dirPin), I2C bus 1

bool encodersConfigured = false;

// PID gains and the following-error fault limit. Zero gains are deliberately
// inert - the loop runs and can report error, but applies no correction -
// until an operator sets real values. This is the "start with Kp small, Ki=0,
// Kd=0" rule from the plan, enforced as the default rather than left to be
// remembered.
struct XYPidState {
  float kp = 0.0f;
  float ki = 0.0f;
  float kd = 0.0f;
  float integralA = 0.0f;
  float integralB = 0.0f;
  float lastMeasuredA = 0.0f;    // for derivative-on-measurement
  float lastMeasuredB = 0.0f;
  bool primed = false;
};
XYPidState xyPid;

// Encoder counts, not steps: correcting in the same units the sensor reports
// avoids a lossy round trip through cm on every control tick.
float xyFollowLimitCounts = 51.0f;    // ~10 full steps at 5.12 counts/step
long xyIntegralClampCounts = 1024;    // +-1/4 revolution; anti-windup

// How often (in step iterations) the loop reads encoders and applies
// correction. Every iteration would mean two I2C transactions between every
// single step pulse, which risks the encoder read itself becoming the speed
// limiter; every few iterations keeps the correction frequent (continuous
// relative to the move, not only at the end) while bounding bus traffic. Start
// conservative; the achievable rate is a hardware question, not a code one.
const int PID_CHECK_EVERY_N_ITERATIONS = 8;

void configureEncoderChannel(EncoderChannel &channel, TwoWire &bus, int sdaPin, int sclPin) {
  if (channel.bus != nullptr && (channel.sdaPin != sdaPin || channel.sclPin != sclPin)) {
    channel.bus->end();
  }
  channel.bus = nullptr;
  channel.sdaPin = sdaPin;
  channel.sclPin = sclPin;
  channel.primed = false;
  channel.faulted = false;
  channel.lastStatus = 0;
  if (sdaPin < 0 || sclPin < 0) {
    return;
  }
  if (bus.begin(sdaPin, sclPin, AS5600_I2C_HZ)) {
    bus.setTimeOut(AS5600_I2C_TIMEOUT_MS);
    channel.bus = &bus;
  }
}

void configureEncoderPins(int sdaA, int sclA, int sdaB, int sclB) {
  configureEncoderChannel(encoderA, Wire, sdaA, sclA);
  configureEncoderChannel(encoderB, Wire1, sdaB, sclB);
  encodersConfigured = (encoderA.bus != nullptr && encoderB.bus != nullptr);
}

// Reads STATUS and RAW ANGLE in one transaction and folds the angle into the
// channel's accumulated position. Returns false on anything that makes the
// reading untrustworthy: a bus error, a magnet that is missing or out of
// range, or a jump of close to half a revolution since the last read - that
// last one means the channel was not polled often enough for the speed the
// axis was moving at, which is a fault, not a value to silently accept.
bool readEncoderChannel(EncoderChannel &channel) {
  if (channel.bus == nullptr) {
    return false;
  }

  TwoWire &bus = *channel.bus;
  bus.beginTransmission(AS5600_ADDRESS);
  bus.write(AS5600_REG_STATUS);
  if (bus.endTransmission(false) != 0 || bus.requestFrom(AS5600_ADDRESS, (uint8_t)3) != 3) {
    channel.faulted = true;
    return false;
  }
  uint8_t status = bus.read();
  uint8_t high = bus.read();
  uint8_t low = bus.read();
  channel.lastStatus = status;

  bool magnetOk = (status & AS5600_STATUS_MD) && !(status & (AS5600_STATUS_ML | AS5600_STATUS_MH));
  uint16_t raw = ((uint16_t)(high & 0x0F) << 8) | low;

  if (!channel.primed) {
    channel.lastRaw = raw;
    channel.primed = magnetOk;
    channel.faulted = !magnetOk;
    return magnetOk;
  }

  int32_t delta = (int32_t)raw - (int32_t)channel.lastRaw;
  // Wrap handling: a delta near +-4096 is really a small step across the
  // 0/4096 boundary, not a big jump. Fold it into the smaller, correct delta.
  if (delta > ENCODER_COUNTS_PER_REV / 2) {
    delta -= ENCODER_COUNTS_PER_REV;
  } else if (delta < -ENCODER_COUNTS_PER_REV / 2) {
    delta += ENCODER_COUNTS_PER_REV;
  }

  // A delta still close to half a revolution after that correction means two
  // consecutive reads were far enough apart in time (or the axis moved fast
  // enough) that which way it wrapped is ambiguous - this is the "must never
  // miss half a revolution" rule from the plan, checked rather than assumed.
  bool ambiguousWrap = labs(delta) > (ENCODER_COUNTS_PER_REV * 3) / 8;

  // A reading taken without a good magnet is noise; keep the last position
  // rather than integrate it.
  if (magnetOk) {
    channel.turns += delta;
    channel.lastRaw = raw;
  }
  channel.faulted = !magnetOk || ambiguousWrap;
  return !channel.faulted;
}

long encoderAccumulatedCounts(const EncoderChannel &channel) {
  return channel.turns;
}

long cmToSteps(float centimeters, float stepsPerCm) {
  return lroundf(centimeters * stepsPerCm);
}
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
void loop() {
  if (!Serial.available()) {
    return;
  }

  String cmd = Serial.readStringUntil('\n');
  cmd.trim();
  if (cmd.length() == 0) {
    return;
  }

  if (cmd == "ID?" || cmd == "ID") {
    printControllerIdentity();
  }
  else if (cmd == "PING") {
    Serial.println("PONG");
  }
  else if (cmd == "STOP") {
    Serial.println("OK STOP");
  }
  else if (handleTestMotorCommand(cmd)) {
  }
  else if (handleSetXYEnableCommand(cmd)) {
  }
  else if (handleSetXYPinsCommand(cmd)) {
  }
  else if (handleSetEncoderPinsCommand(cmd)) {
  }
  else if (handleEncoderQueryCommand(cmd)) {
  }
  else if (handleEncoderProbeCommand(cmd)) {
  }
  else if (handleEncoderScanCommand(cmd)) {
  }
  else if (handleSetXYPidCommand(cmd)) {
  }
  else if (handleXYPidQueryCommand(cmd)) {
  }
  else if (handleSetXYFollowLimitCommand(cmd)) {
  }
  else if (handleSetXYLimitsCommand(cmd)) {
  }
  else if (handleMoveXYZCommand(cmd)) {
  }
  else if (handleMoveXYCommand(cmd)) {
  }
  else if (handleGotoXYCommand(cmd)) {
  }
  else if (handleCircleXYCommand(cmd)) {
  }
  else if (handleMoveXCommand(cmd)) {
  }
  else if (handleCalibrateXYCommand(cmd)) {
  }
  else if (handleSetZPinsCommand(cmd)) {
  }
  else if (handleSetZLimitsCommand(cmd)) {
  }
  else if (handleMoveZCommand(cmd)) {
  }
  else if (handleCalibrateZCommand(cmd)) {
  }
  else {
    Serial.println("ERR UNKNOWN CMD");
  }
}

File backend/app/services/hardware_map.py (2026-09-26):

import json
from datetime import datetime, timezone
from pathlib import Path

from pydantic import ValidationError

from app.models.function_manifest import FunctionManifest
from app.models.hardware_map import (
    HardwareBoardConnectionStatus,
    HardwareBoardMapping,
    HardwareConnectorMapping,
    HardwareConnectorPin,
    HardwareDeviceMapping,
    HardwareGroupMapping,
    HardwareMap,
    HardwareMapSaveResponse,
    HardwarePinMapping,
)
from app.services.serial_ports import list_serial_ports


class HardwareMapError(RuntimeError):
    pass


def _pin(pin_id: str, signal: str, gpio: int | str, function_input_key: str | None = None) -> HardwarePinMapping:
    return HardwarePinMapping(
        id=pin_id,
        signal=signal,
        gpio=str(gpio),
        function_input_key=function_input_key,
    )


class HardwareMapService:
    def __init__(self, hardware_map_path: Path, active_connector_groups=None) -> None:
        self._hardware_map_path = hardware_map_path
        # Which tool groups are docked on a connector right now. Injected so
        # tests do not read the machine's connector state.
        self._active_connector_groups = active_connector_groups

    def active_connector_group_ids(self) -> set[str]:
        if self._active_connector_groups is not None:
            return set(self._active_connector_groups())
        from app.services.pogo_connector import connector_state_store

        return connector_state_store.active_group_ids()

    def _group_covers(self, group: HardwareGroupMapping, device: HardwareDeviceMapping) -> bool:
        # A tool's USB controller belongs to the tool even when the group only
        # names it as usb_board_id: everything on that board leaves with it.
        return (
            device.id in group.member_ids
            or bool(device.board_id and device.board_id in group.member_ids)
            or bool(device.board_id and group.usb_board_id and device.board_id == group.usb_board_id)
        )

    def _resolve_gpio(self, hardware_map: HardwareMap, device: HardwareDeviceMapping, gpio: str) -> str:
        """Pi GPIO for a device pin. Hardware on a connector names connector
        pins (SDA, TXD, ...); the connector says which GPIO each one is."""
        connector = next((c for c in hardware_map.connectors if c.id == device.board_id), None)
        if connector is None:
            return gpio
        pin = next((p for p in connector.pins if p.name == gpio), None)
        return pin.gpio if pin else gpio

    def _undocked_tool_group(
        self,
        hardware_map: HardwareMap,
        device: HardwareDeviceMapping,
        active_group_ids: set[str] | None = None,
    ) -> HardwareGroupMapping | None:
        """The connector tool this device belongs to, if that tool is not the
        one docked. Hardware on an absent tool must not be driven: its pins are
        wired to whatever tool *is* on the head."""
        tool_groups = [
            group for group in hardware_map.groups if group.connector_id and self._group_covers(group, device)
        ]
        if not tool_groups:
            return None
        active = self.active_connector_group_ids() if active_group_ids is None else active_group_ids
        if any(group.id in active for group in tool_groups):
            return None
        return tool_groups[0]

    def load_map(self) -> HardwareMap:
        if not self._hardware_map_path.exists():
            return self._default_map()

        try:
            with self._hardware_map_path.open("r", encoding="utf-8") as hardware_map_file:
                payload = json.load(hardware_map_file)
            return HardwareMap.model_validate(payload)
        except json.JSONDecodeError as exc:
            raise HardwareMapError(
                f"hardware-map.json contains invalid JSON: {exc.msg}"
            ) from exc
        except ValidationError as exc:
            raise HardwareMapError(
                f"hardware-map.json failed validation: {exc.errors()[0]['msg']}"
            ) from exc

    def _sync_device_enabled_with_groups(self, hardware_map: HardwareMap) -> HardwareMap:
        """A device's stored enabled flag always mirrors the board and any
        hardware groups it belongs to - turning a board or group off shows
        every device under it as off, and turning it back on shows them all
        as on again, like a breaker cutting power to everything downstream.
        No per-device override survives independent of its board/group: if a
        specific device needs to stay off, that has to be set again after the
        board or group is re-enabled.
        """
        board_enabled = {board.id: board.enabled for board in hardware_map.boards}
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

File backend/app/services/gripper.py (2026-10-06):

"""Two hobby servos that open and close the gripper tool.

A hobby servo cannot report where it is: its first pulse makes it jump to the
commanded angle at full speed. So the service assumes the gripper starts where
it is parked in the rack - closed - sends that first, and ramps every later
move in small steps from the last angle it commanded. As long as the claws
really are closed when the tool is picked up, nothing ever snaps.

Pulses keep running after a move so the claws hold what they grip; a servo
without pulses goes limp. `release()` stops them, which is what a drop wants.

Pulses come from lgpio, which times them in software on any GPIO. The PIO
based `pwm-pio` overlay would give hardware-timed pulses on the same pins;
switching is contained to `_LgpioServos`.
"""

from __future__ import annotations

import os
import threading
import time
from dataclasses import dataclass, field

SERVO_FRAME_HZ = 50
RAMP_STEP_SECONDS = 0.02


@dataclass(frozen=True)
class ServoSettings:
    gpio: int
    open_deg: float
    closed_deg: float
    pulse_min_us: float = 500.0
    pulse_max_us: float = 2500.0

    def pulse_us(self, angle_deg: float) -> int:
        """-90..+90 deg mapped onto the pulse range, centre at its middle."""
        clamped = max(-90.0, min(90.0, angle_deg))
        span = self.pulse_max_us - self.pulse_min_us
        return round(self.pulse_min_us + (clamped + 90.0) / 180.0 * span)


class _LgpioServos:
    def __init__(self) -> None:
        import lgpio  # imported lazily: absent on development machines

        self._lgpio = lgpio
        self._handle = lgpio.gpiochip_open(0)
        self._claimed: set[int] = set()

    def pulse(self, gpio: int, width_us: int) -> None:
        if gpio not in self._claimed:
            self._lgpio.gpio_claim_output(self._handle, gpio, 0)
            self._claimed.add(gpio)
        self._lgpio.tx_servo(self._handle, gpio, width_us, SERVO_FRAME_HZ)

    def stop(self) -> None:
        for gpio in list(self._claimed):
            self._lgpio.tx_servo(self._handle, gpio, 0)
            self._lgpio.gpio_free(self._handle, gpio)
        self._claimed.clear()


@dataclass
class SimulatedServos:
    pulses: dict[int, list[int]] = field(default_factory=dict)
    stopped: bool = False

    def pulse(self, gpio: int, width_us: int) -> None:
        self.stopped = False
        self.pulses.setdefault(gpio, []).append(width_us)

    def stop(self) -> None:
        self.stopped = True


def _simulating() -> bool:
    return os.getenv("ROBOT_GPIO_SIMULATE", "").strip().lower() in {"1", "true", "yes", "on"}


class GripperService:
    def __init__(self, driver=None, sleep=time.sleep) -> None:
        self._driver = driver
        self._sleep = sleep
        self._lock = threading.Lock()
        # Last commanded angle per GPIO. Empty means "assume parked closed".
        self._angles: dict[int, float] = {}
        # What the last move used, so a drop can close the same servos.
        self._last: tuple[list[ServoSettings], float] | None = None

    def _servos(self):
        if self._driver is None:
            self._driver = SimulatedServos() if _simulating() else _LgpioServos()
        return self._driver

    def move(self, servos: list[ServoSettings], target: str, ramp_deg_per_s: float) -> dict[int, float]:
        """Ramp every servo to its open or closed angle together."""
        if target not in {"open", "close"}:
            raise ValueError(f"Unknown gripper action '{target}'; use open or close.")
        with self._lock:
            driver = self._servos()
            starts = {}
            for servo in servos:
                if servo.gpio not in self._angles:
                    # First pulse since start-up: the parked position, so a
                    # gripper that really is closed does not move.
                    self._angles[servo.gpio] = servo.closed_deg
                    driver.pulse(servo.gpio, servo.pulse_us(servo.closed_deg))
                starts[servo.gpio] = self._angles[servo.gpio]

            goals = {s.gpio: (s.open_deg if target == "open" else s.closed_deg) for s in servos}
            travel = max((abs(goals[g] - starts[g]) for g in goals), default=0.0)
            steps = max(1, round(travel / max(ramp_deg_per_s, 1.0) / RAMP_STEP_SECONDS)) if travel else 0
            for step in range(1, steps + 1):
                for servo in servos:
                    angle = starts[servo.gpio] + (goals[servo.gpio] - starts[servo.gpio]) * step / steps
                    driver.pulse(servo.gpio, servo.pulse_us(angle))
                self._sleep(RAMP_STEP_SECONDS)
            for servo in servos:
                self._angles[servo.gpio] = goals[servo.gpio]
            self._last = (list(servos), ramp_deg_per_s)
            return dict(self._angles)

    def release(self) -> None:
        """Stop the pulses; the servos go limp where they are."""
        with self._lock:
            if self._driver is not None:
                self._driver.stop()
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

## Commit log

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2026-04-02 fixed advanced setting bugs also added parallel dispensing
    [handler.py, main.ino, syringe_controller.py]
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2026-06-22 feat: add workflow broken-reference placeholders
    [test_schema_compatibility.py]
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2026-07-05 fixed the pi gpio pins funtionality
    [gpio_backend.py, test_gpio_backend.py]
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2026-08-08 Rebuild safety, physical state and controller identity
    The orchestration layer above the hardware drivers was unreliable in three
    ways: E-Stop was advisory, the machine lied about which tool it was holding,
    and flashing could target the wrong board. This addresses the first two and
    lays the groundwork for the third. The drivers themselves are untouched -
    they carry hardware-tuned behaviour that cannot be re-derived off the machine.
    One safety authority (app/core/safety.py)
    Five services each owned a private stop flag and /rearm cleared two of them,
    so whether motion was blocked depended on which service you asked. There is
    now a single threading.Event, shared by reference with every motion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
    [fingerprint.py, gantry_controller.py, main.ino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]
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2026-08-10 Stop the test suite from driving the real gantry; harden GPIO fallback
    Two problems that only appeared once this ran on the Pi.
    The routing tests in test_raspberry_gantry call the full calibrate_xy /
    move_xy path. On the Windows machine they were written on there was no GPIO
    library, so the service quietly fell back to simulation and they passed. On
    the Pi they configure real pins and step real motors, then fail on whatever
    the real limit switches happen to read. They only ever assert which
    controller a request is routed to, so they now pin ROBOT_GPIO_SIMULATE
    explicitly. The fallback test additionally denies lgpio, since on the Pi it
    really is installed and the service would otherwise reac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
    [gpio_backend.py, test_gpio_backend.py, test_raspberry_gantry.py]
2026-08-10 Make the controller identity handshake actually work
    render_identity_header existed but nothing ever called it, so every flashed
    board answered ID? with an empty identity. Preflight could only read that as
    "cannot verify", so runs reflashed every controller anyway - the handshake was
    inert.
    flash/build now stamp generated_identity.h into the sketch immediately before
    compiling. build_firmware_bundle assembles what should be on a controller: the
    routine ids from manifests targeting that board, the pin table the Hardware Map
    resolves for its devices, and hashes of the firmware sources. Any change to
    those changes the fingerprint, so the board stops matching and is reflashed;
    a rebuild that ch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
    [fingerprint.py, test_identity_flash_path.py]
2026-08-10 Bring up the syringe controller: both boards now self-identify
    The syringe controller had no workspace directory at all, which is why
    plan_workflow_firmware could not resolve it, downgraded it to "externally
    programmed", and excluded it from flashing - the run then proceeded against
    whatever firmware happened to be on it. Its firmware only lived at
    firmware/syringe-controller/, outside any workspace, so the app had no way to
    build or flash it.
    Adds the esp32 controller-x83xnc workspace with that firmware, and points the
    syringe manifests at it. dispense previously declared builder_board_id
    ttyUSB1, which is the Z board, so its routine was being attributed to the
    wrong controller entirely.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
    [fingerprint.py, main.ino]
2026-08-10 Runs now verify controllers instead of reflashing them
    The identity handshake worked but nothing used it: the run path still called
    flash unconditionally, so every workflow reflashed every board before starting
    even when the firmware was already correct.
    The flash endpoint takes skip_if_current, and the run path passes it. A board
    already running the expected firmware is skipped; one reporting a different
    controller id is refused rather than overwritten. The builder's Flash button
    deliberately leaves it false - clicking Flash means flash it.
    Also exposes GET /boards/{id}/preflight so the verdict can be inspected
    without flashing anything.
    Measured on the real machine with both controllers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
2026-08-10 Say what is actually blocking motion, not just "emergency stop"
    The stop flag is shared with the safety controller and stays set while a
    physical fact is unconfirmed - long after the stop itself is over. The
    operator then gets "Z axis motion stopped by emergency stop" and goes hunting
    for a limit switch that is not pressed, when the real blocker is an unanswered
    question about what is on the gantry.
    Motion errors now name the outstanding facts and the way out. Reported from
    the machine: calibrate_z failed with the old message while all four Z limit
    switches read released, and the actual blocker was toolhead.held, imported
    from the legacy state file as uncertain because that format could not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
2026-08-10 Move the dispense blueprint onto the syringe controller's workspace
    Function manifests are generated from the workspace blueprints, and the
    workspace a blueprint sits in decides its builder_board_id. dispense lived in
    the Z controller's workspace, so it kept regenerating as belonging to that
    board - an earlier fix to the manifest was silently overwritten on the next
    sync, and the Z board's firmware bundle claimed a dispense routine it does not
    implement.
    Moving the blueprint fixes it at the source: dispense now regenerates as
    controller-x83xnc and stays there.
    Both controllers now preflight ok with correct routine sets, and the safety
    latch is armed with nothing outstanding.
    Co-Authored-B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
2026-08-10 Give the controllers stable ids instead of port-derived ones
    The Hardware Map named the boards after the ports they happened to enumerate
    on (ttyUSB0, ttyUSB1) while the firmware reports stable ids
    (controller-ykkl80, controller-x83xnc). Preflight compares the two and
    correctly refused to flash, but here the "mismatch" was only two naming
    schemes for the same board, so a syringe run failed with "the board on
    /dev/ttyUSB0 reports it is controller-ykkl80, but the Hardware Map expects
    ttyUSB0".
    Port-derived ids cannot work here: the ports renumbered twice in a single
    session. The boards are renamed to the ids their firmware already reports,
    keeping labels, device assignments and pins untouched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
2026-08-10 Implement the dispense block instead of returning "not implemented"
    dispense shipped as the generated placeholder handler, so testing the block
    reported status "not_implemented" while the 7_syringe preset - which does
    exactly the same thing - worked. The placeholder is only written when no
    handler exists, so a real one sticks.
    The input mapping and result shape now live in one place rather than being
    spelled out per handler. That duplication had already caused a real defect:
    the per-head step/dir pins were added to the preset block so the firmware
    would use the wired pinout, and the plain dispense block never got the same
    fix. Both blocks are now thin wrappers over the shared path.
    Co-Auth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
    [handler.py, syringe_controller.py]
2026-08-10 Stop resetting the ESP32 just to ask it who it is
    The identity handshake opened the port the ordinary way, which toggles DTR/RTS
    and therefore resets the board, so it had to sleep 2s waiting for it to boot
    before it could ask anything. That was paid per board, on every run and every
    block test - about 7s per controller for a question the board can answer
    immediately.
    The port is now opened without asserting those lines, and anything already in
    flight is drained until the line goes quiet rather than for a fixed interval.
    The fixed interval was the trap: a first attempt with a short sleep read the
    board's boot banner ("OK XY PINS ...") as the answer to ID?, which parses as
    "no identity" and r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
    [transport.py]
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2026-08-10 Add the execution plan compiler (Phase 3 foundation)
    Compiles a saved workflow into a validated ExecutionPlan before anything runs:
    resolves nodes and typed edges, finds the start, identifies real join points,
    works out which cycles are legitimate loop bodies and rejects the ones that are
    not, and reports unreachable blocks and dead error paths.
    This is the piece the browser-side runner never had. It walked the graph as a
    plain DFS over the edge array, which produced most of the run defects at once
    (3-6): order followed the order edges happened to be drawn, a node fed by two
    branches fired on whichever arrived first, `if` ran both branches because every
    outgoing edge was followed, and error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
    [test_engine_plan.py]
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2026-08-10 Let the engine drive a run, with the browser executing
    The scheduler was correct but nothing called it. This connects it: the
    browser opens a run, is handed the nodes that are due, executes them, and
    reports each result, which the engine turns into whatever that makes ready
    next.
    Execution deliberately stays in the browser - hardware resolution, firmware
    flashing and the safety interlocks already live there and work. Only the
    decisions move: which branch an if takes, how many times a loop runs, who
    waits for whom. Those are the ones that were wrong.
    run_plan is refactored into PlanRunner, a steppable object, with run_plan
    kept as a thin loop over it so the existing tests still describe the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
    [main.py, test_engine_routes.py, test_engine_scheduler.py]
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2026-08-10 Write down what each run actually did
    A run moves a gantry, dispenses volumes, homes an axis. When something looks
    wrong hours later, "what did the machine actually do" needed an answer that
    did not depend on a browser tab still being open - the run session lives in
    memory and is gone the moment the run ends.
    One JSONL file per run: what started, every block that ran and what it
    returned, every decision the engine made off the back of it, and how the run
    ended. Append-only, because a record that gets rewritten as the run proceeds
    can lose the entry that explains the failure. Write errors are swallowed and
    disable the journal rather than propagating - stopping mid-dispense because
    a log line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
    [test_engine_journal.py, test_engine_routes.py, test_engine_scheduler.py]
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2026-08-10 Run compound blocks through the engine as well
    Compound blocks kept their own copy of the walk that made control flow wrong:
    a depth-first pass over the inner edge array, every node visited once, every
    outgoing edge followed. So collapsing an If and its branches into one block
    quietly brought "runs both branches" back inside the wrapper - and compounds
    are built by selecting whatever is on the canvas, so a control block can
    easily end up in one.
    The inner graph now goes through the engine like any other graph, which
    means compile_plan needed a way to be told where to start. A compound is a
    fragment: its entry node is recorded on the block, and its other roots are
    not entry points that shoul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
    [test_engine_plan.py]
2026-08-12 Power motor drivers only while they are being used
    Idle steppers hold full current and get hot for nothing. The drivers now sit
    disabled until something wants to move, on two rules:
    Enable early - the line is asserted and left to settle for a second before
    the first step, so the supply sees the load ramp rather than a step change
    coincident with motion. Stepping into a driver that just came out of standby
    is how you get a stall on the first move.
    Do not power down between blocks - releasing starts a linger timer rather
    than cutting power, so five gantry moves in a row stay enabled throughout and
    pay the settle delay once. Power drops only when nothing has wanted the
    motors for the whole wi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
    [main.py, motor_power.py, test_motor_power.py]
2026-08-12 Add the peristaltic pump block and its firmware routine
    Five pumps on the Z/pump ESP32 (13/14, 27/26, 25/33, 22/23, 4/16), driven
    per-pump rather than as a bank: they feed different reagents and routinely
    want different rates. A bank protocol cannot express "pump 2 only", whereas
    running all five together is just five commands issued at once.
    Firmware: PUMP RUN interleaves the active pumps on due-time in one loop, so
    each keeps its own rate without needing a timer peripheral per pump. Rollover
    -safe (unsigned micros() subtraction) and it checks for STOP between steps,
    so a dispense can be aborted mid-run. Compiles at 317,120 bytes (24%), up
    from 315,472.
    Also adds SET MOTOR ENABLE PIN / MO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
    [handler.py, main.ino, test_peristaltic_pumps.py]
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2026-08-13 Pull the CoreXY enable line low, not high
    The gantry drivers are TB6600s, and a TB6600's opto-isolated ENABLE input
    *disables* the driver when energised - leaving ENABLE disconnected is what
    makes one run. The enable line shipped in 07121fe drove it high to enable,
    copied from the TB67S109s on the Z/pump board, which is exactly backwards for
    this hardware.
    That failure is a quiet one: the software reports the motors as powered and
    the gantry simply refuses to move. Worth a test, so there is one.
    Polarity is now a property of the power domain rather than an assumption
    baked into the service, because the two boards genuinely disagree - GPIO 17
    high wakes a TB67S109, GPIO 25 low wakes a TB660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
    [motor_power.py, test_motor_power.py]
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2026-08-13 Stop releasing the enable pin at the end of every move
    Two bugs that together looked exactly like inverted polarity, and sent this
    round in a circle for a while.
    _cleanup_gpio released the enable pin along with the step, dir and limit pins
    at the end of each move. But the power service owns that pin across moves -
    that is what lets power linger between blocks instead of cycling. Releasing
    it reverted the pin to an input, so when the linger timer fired three seconds
    later the power-down threw "channel has not been set up as an OUTPUT".
    That exception then left the domain believing it was still powered, so the
    next acquire() saw "already on" and returned without driving anything - while
    setu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
    [motor_power.py]
2026-08-13 Let a Z calibration set the Z blocks' defaults and ranges
    The XY blocks already do this: what an operator measures during calibration
    becomes what the next block offers, and the usable travel derived from it
    becomes the allowed range on the move blocks. The Z blocks did not, so a
    corrected track length had to be retyped into every Move Z block, and Move Z
    would happily accept a target the carriage cannot physically reach.
    Move Z now carries min and max, so the editor shows "Allowed range: 0 - 59"
    the way the XY blocks do, and Calibrate Z adopts the track lengths and buffer
    it was run with as its own defaults.
    Per side rather than shared, unlike XY: the two screws are calibrated
    independent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
    [handler.py]
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2026-08-13 Assert the enable line on every move, not just the first
    The gantry dropped power as soon as a second move started. _setup_gpio runs
    at the beginning of every move and re-claimed the enable GPIO at its disabled
    level; acquire then saw the domain already marked powered, trusted that, and
    returned without writing anything. So the line sat disabled for the whole
    move while the service cheerfully reported it on - which is exactly what
    running Move Gantry XY after a calibration produced.
    This is the second time the same shape of bug has bitten, so the assumption
    is gone rather than patched: acquire now writes the line every time. It is a
    physical thing other code touches - a driver re-claiming i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
    [motor_power.py, test_motor_power.py]
2026-08-13 Re-touch X home during a tool change
    Worn bearings lose the occasional step. Everywhere else that is tolerable; at
    the tool rack it is not, because the head has to meet its hooks - which is
    where the reported 1% of failures land.
    The tool-change sequence already drives X from the clearance offset to the
    rack at X 0, and X 0 is defined by the X min slow touch during calibration.
    So the switch is right there: re-touching it costs one short probe and gives
    back every step X has lost since the last home.
    Placed after the clearance approach and before anything engages. That is the
    only safe point in the sequence - the carriage is clear of the hooks and is
    not carrying a tool into them.
    Y is de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
    [handler.py]
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2026-08-17 Make the tool-change probe and rack speeds editable
    Both were hardcoded. The probe speed was a module constant, so tuning it
    meant editing source; the hop across to the tool's Y borrowed the main
    approach speed, so slowing it meant slowing the whole approach.
    A tool change now has three speeds doing three distinct jobs:
    approach_speed_rpm getting out to the rack
    rack_approach_speed_rpm crossing to the tool's own Y (default 200)
    home_speed_rpm the X and Y re-home probes (default 20)
    Engagement stays fixed and slow at 50 - that one is not a preference.
    The rack hop is separate because it ends where engagement begins, so it is
    worth being able to slow it without slowi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
    [handler.py]
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2026-08-29 Stand off further when returning a tool than when collecting one
    Clearance was one shared rack setting used by both operations, so it could
    not be right for both. Approaching an empty slot only needs enough room to
    clear the hooks; backing away with a tool hanging off the head wants
    considerably more, because the tool sticks out further than the carriage.
    Now pickup_clearance_cm (2 cm) and drop_clearance_cm (10 cm), both editable.
    The drop clearance also applies to the automatic drop inside a pickup - when
    a tool is already held it goes back to its slot first, and that is a drop, so
    it gets the drop standoff.
    263 tests pass.
    [handler.py]
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2026-08-29 Implement stages 0-2 of closed-loop XY, PID scaffolded and inert
    Per docs/CLOSED_LOOP_XY_PLAN.md. New ESP32 workspace "xy-closed-loop"
    (placeholder id - no board has been built or connected yet), based on the
    proven ttyUSB0 CoreXY firmware rather than written from scratch, plus:
    - AS5047P SPI driver, wrap accumulation, ambiguous-wrap detection (a delta
    still near half a revolution after unwrapping means two reads were too far
    apart in time to trust, per the plan's "must never miss half a revolution"
    rule).
    - Following-error monitoring inside the existing, proven CoreXY stepping
    loop: every Nth iteration reads both encoders and halts the move if either
    motor's error exceeds a tunab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
    [gantry_controller.py, hardware_map.py, main.ino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]
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2026-09-23 Add the dynamic pogo connector: tools as Hardware Map groups
    The toolhead connector carries GPIO 2/3/14/15 and the syringe pump's USB.
    Only groups attach to it; each group is one tool with per-pin modes, an
    optional USB controller, a verification method and an optional rack slot.
    Connect Tool / Disconnect Tool blocks select the active tool, pick-up does
    it automatically, and hardware on an undocked tool is refused with a reason.
    Verification fails loudly and leaves the connector empty.
    [handler.py, hardware_map.py, test_pogo_connector.py]
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2026-09-23 Check pogo contact during pick-up, with retries
    Optional on Pick Up Toolhead: at the tool position, before the dip that
    hooks the tool, wait (1 s default) and check TXD-RXD are shorted. A miss
    backs out to the clearance position and slides in again, up to N retries.
    Exhausted retries leave the head at clearance, recorded as empty. A check
    that could never pass (the slot's tool uses TXD/RXD) is refused before
    anything moves.
    [handler.py]
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2026-09-23 Resync the pogo connector when the operator confirms the held tool
    Confirming a slot connects that slot's tool; confirming an empty head
    empties the connector. A failed connector check never rejects the answer:
    the connector is left empty and the reason is kept for the editor to show.
    [test_pogo_connector.py]
2026-09-23 Add a no-motion TXD-RXD contact check endpoint
    POST /api/hardware-map/connectors/check-contact drives only TXD and reports
    whether RXD follows. Used to tell a missing short from a wiring or position
    problem without moving the gantry.
    [hardware_map.py, test_pogo_connector.py]
2026-09-23 Check tool contact after the dip, once the tool is seated
    On the machine the pogo pins only touch once the tool is hooked: a pick-up
    of slot 1 with the check at the tool position failed all three attempts,
    while the same tool seated on the head read a solid short.
    The check now runs after the dip and lift. A miss unhooks the tool along
    the drop's release path, backs out to clearance and picks it up again.
    Exhausted retries leave the tool in its slot and the head recorded empty.
    [handler.py]
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2026-09-28 Switch closed-loop XY from AS5047D (SPI) to AS5600 (I2C) encoders
    Procurement changed. The AS5600 is 12-bit (4096 counts/rev, 5.12 counts
    per step) and answers at a fixed I2C address, so the two encoders cannot
    share a bus: encoder A runs on the ESP32's Wire, encoder B on Wire1, each
    with its own SDA/SCL. One 3-byte read returns STATUS and RAW ANGLE, so a
    missing or badly placed magnet is a read fault, and a 2 ms bus timeout
    keeps a disconnected encoder from hanging the stepping loop.
    SET ENCODER PINS now takes four pins (sdaA sclA sdaB sclB); ENCODER?
    reports the STATUS byte too. The follow-error default scales to 51
    counts (~10 steps) and the integral clamp to a quarter turn (1024). The
    m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
    [gantry_controller.py, main.ino, test_gantry_controller_commands.py]
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2026-10-06 Add the Gripper block and the gripper tool in slot 6
    Two hobby servos on the pogo SCL (left) and SDA (right) pins, opened and
    closed together, mirrored. A servo cannot report its position, so the first
    pulse is the parked (closed) position and every move is ramped from the last
    commanded angle; the servos keep holding afterwards. Closed defaults to
    left -90 / right +90, the rack position; open to +30 / -30. Angles and pulse
    ranges are per-servo advanced settings. Dropping the tool, directly or as
    part of a pick-up, closes the gripper and stops its pulses first.
    Also isolate the gantry encoder integration tests from real serial ports:
    they failed whenever no ESP32 was plugged in.
    Co-Authore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
    [gripper.py, handler.py, test_gantry_controller_commands.py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]
2026-10-06 Add ENCODER PROBE and ENCODER SCAN diagnostics to the closed-loop firmware
    PROBE reports per bus whether anything answers at the AS5600 address and
    the raw Wire error (2 = no ACK, 5 = bus timeout); SCAN lists every address
    that answers. Used on the first real encoder: a timeout turned out to be
    swapped SDA/SCL, and an empty bus points at power or wiring.
    [main.ino]
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
